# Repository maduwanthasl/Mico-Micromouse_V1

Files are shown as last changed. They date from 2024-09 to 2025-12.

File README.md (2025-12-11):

# 🐭 Mico - Micromouse V1

Welcome to the repository for **Mico**, my custom-designed micromouse robot! This project involved extensive research, component selection, PCB design, and firmware development, all aimed at building a highly capable and efficient micromouse for maze-solving applications.

## 📑 Table of Contents

1. [Project Overview](#project-overview)
2. [Hardware Components](#hardware-components)
3. [Component Comparison](#component-comparison)
4. [PCB Design](#pcb-design)
5. [Microcontroller - STM32 Blue Pill](#microcontroller---stm32-blue-pill)
6. [Firmware Development](#firmware-development)
7. [Getting Started](#getting-started)
8. [Acknowledgments](#acknowledgments)

## 📝 Project Overview

The goal of this project was to build a fully functional micromouse named **Mico** from scratch. This involved careful consideration of hardware, custom PCB design, and firmware development. Throughout the process, I selected and evaluated various components to ensure optimal performance and compatibility.

## 🔧 Hardware Components

Mico is built using carefully chosen components to maximize performance and reliability. Some of the key components include:

- **Microcontroller (MCU)**: STM32 Blue Pill
- **Power Supply**: 3.3V regulator
- **Motor Driver**: [Specify Motor Driver Here]
- **Sensors**: Infrared emitters and receivers for maze sensing
- **Motors**: Precision motors with encoders for accurate movement
- **Additional Components**: Coupling capacitors (100nF, 100V) for noise reduction, etc.

## 🔍 Component Comparison

| **Component** | **Option 1** | **Option 2** | **Notes** |
|---|---|---|---|
| **Microcontroller**  | STM32 | ATmega328P | STM32 chosen for better performance and support for PWM control |
| **Motor Type** | N20 Motor with Encoder | Coreless Motor with Custom Encoder | N20 with encoder used due to budget constraints and time |
| **Battery** | 7.4V LiPo (Downconversion) | 3.7V LiPo (Upconversion) | Upconversion method preferred for weight reduction |
| **IR Sensors** | TOF Sensors | IR Emitter and Phototransistor | IR Emitter chosen; TOF needs multiplexer, increasing response time |
| **Power Regulator**  | AM1117 (3.3V) | MT3608 Step-Up Converter | MT3608 chosen for efficient power conversion |
| **Motor Driver** | TB6612FNG | L298N | TB6612FNG preferred for compact design and compatibility |

_Table 1: Comparison of Key Components for MICO Micromouse Robot_

## 🖥️ PCB Design

I designed a custom PCB specifically for Mico to organize and integrate the various components effectively. The PCB design process involved:

- Component selection based on performance requirements.
- Layout and routing in Altium Designer.
- Prototyping and testing to ensure functionality.

The final PCB was successfully manufactured and assembled, forming the core hardware of the micromouse.

## ⚙️ Microcontroller - STM32 Blue Pill

Initially, I considered using the STM32 Black Pill due to its higher processing capability. However, due to the limited number of available analog channels, I opted for the **STM32 Blue Pill**, which provided the necessary analog inputs for the sensors. The Blue Pill proved to be reliable and sufficient for Mico’s control system.

## 📝 Firmware Development

The firmware for Mico was developed using **STM32CubeIDE**. Key aspects of the firmware include:

- **Sensor Data Processing**: Collects and processes data from the infrared sensors to detect walls and make navigational decisions.
- **Motor Control**: Controls the speed and direction of the motors for precise movement.
- **Maze Solving Algorithm**: Implements a maze-solving algorithm to navigate and solve mazes autonomously.

The firmware was written in C, leveraging various STM32 libraries for peripheral management and efficient control.

## 🚀 Getting Started

To get started with Mico's firmware and hardware setup:

1. **Clone the Repository**:
   ```bash
   git clone https://github.com/maduwanthasl/Mico-Micromouse_V1.git
   cd Mico-Micromouse_V1

## 🙏 Acknowledgments
This project was made possible thanks to the support and resources available through the open-source and embedded systems community.

Enjoy exploring Mico’s journey through maze-solving and micromouse challenges! Contributions and feedback are welcome.

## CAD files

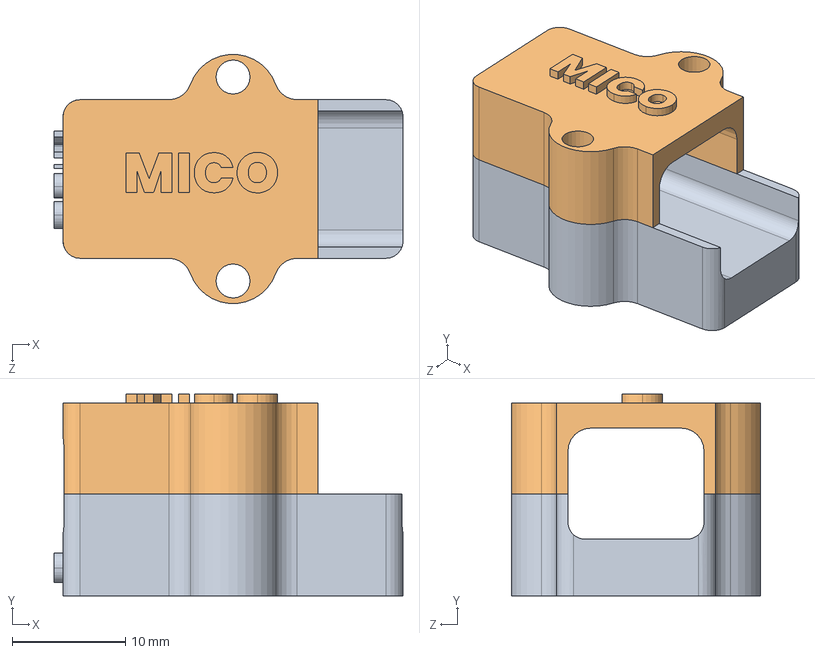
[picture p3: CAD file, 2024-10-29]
CAD files/motor assemble.SLDASM
30.8 x 17.8 x 22.0 mm
motor mounting bracket
Top mounting

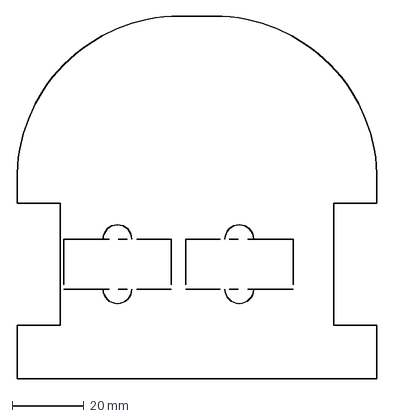
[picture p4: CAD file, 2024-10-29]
Board shape/Mico pcb board shape-2.DXF
100.8 x 101.2 mm

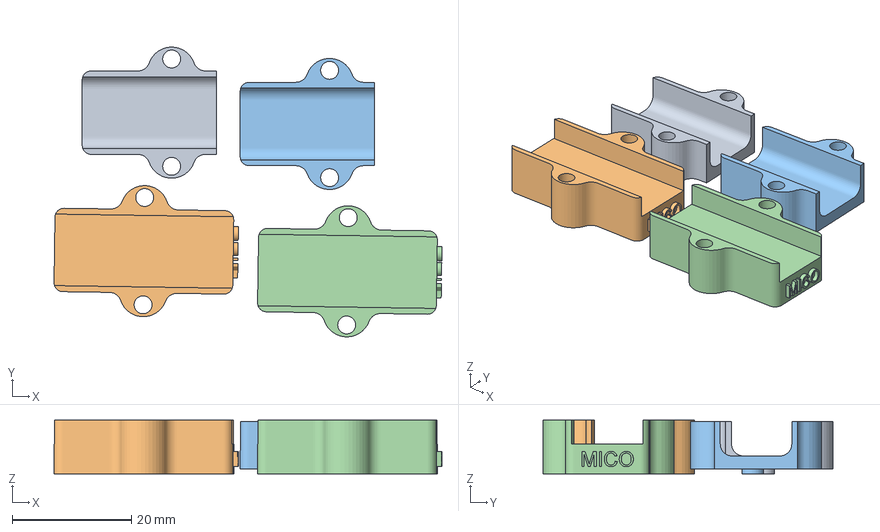
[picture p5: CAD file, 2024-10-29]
CAD files/3d slice parts/SCP_Top mounting.3mf
65.1 x 48.6 x 9.00 mm
Top mounting.STL
motor mounting bracket-L.STL
Top mounting.STL(1)
motor mounting bracket-L.STL(1)

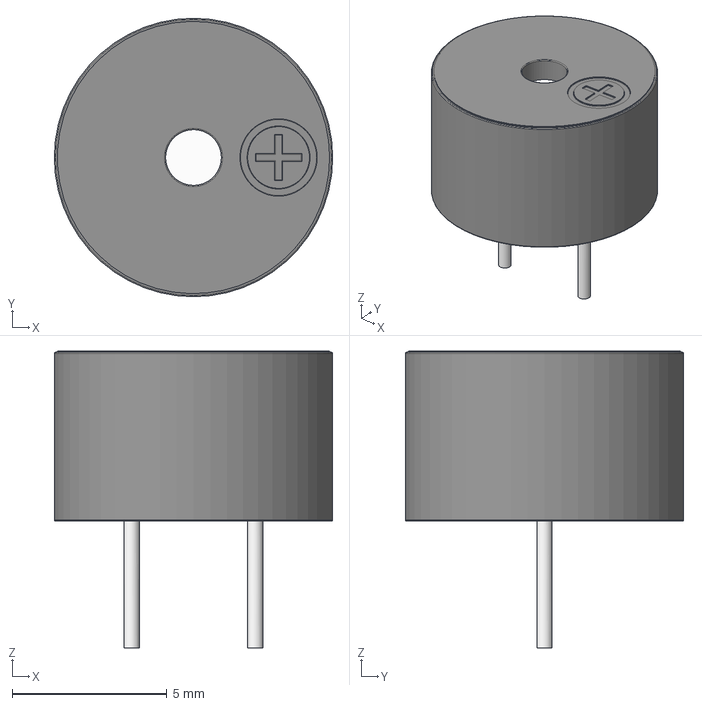
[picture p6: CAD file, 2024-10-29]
CAD files/buzzer-kls3-mt-09-1.snapshot.1/KLS3-MT-09.step
9.00 x 9.00 x 9.60 mm

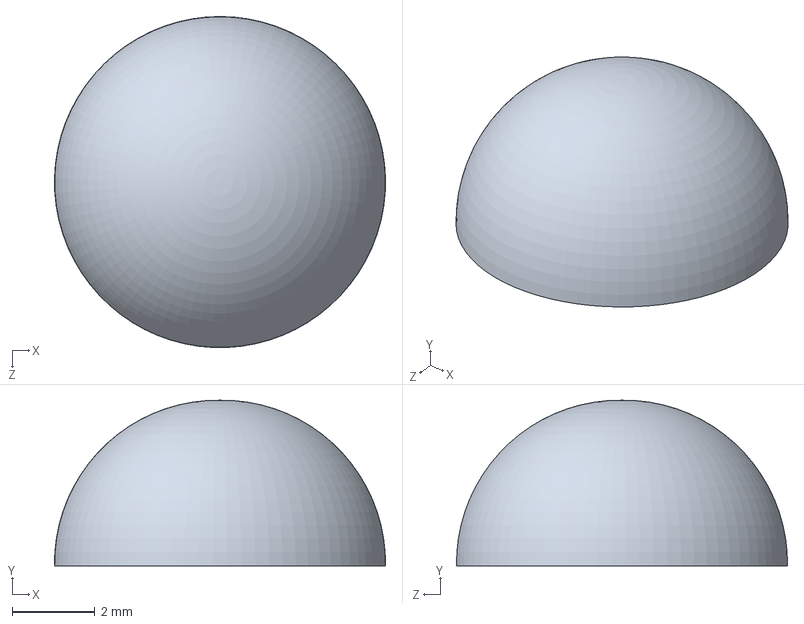
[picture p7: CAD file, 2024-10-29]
CAD files/goal.SLDPRT
8.00 x 4.00 x 8.00 mm

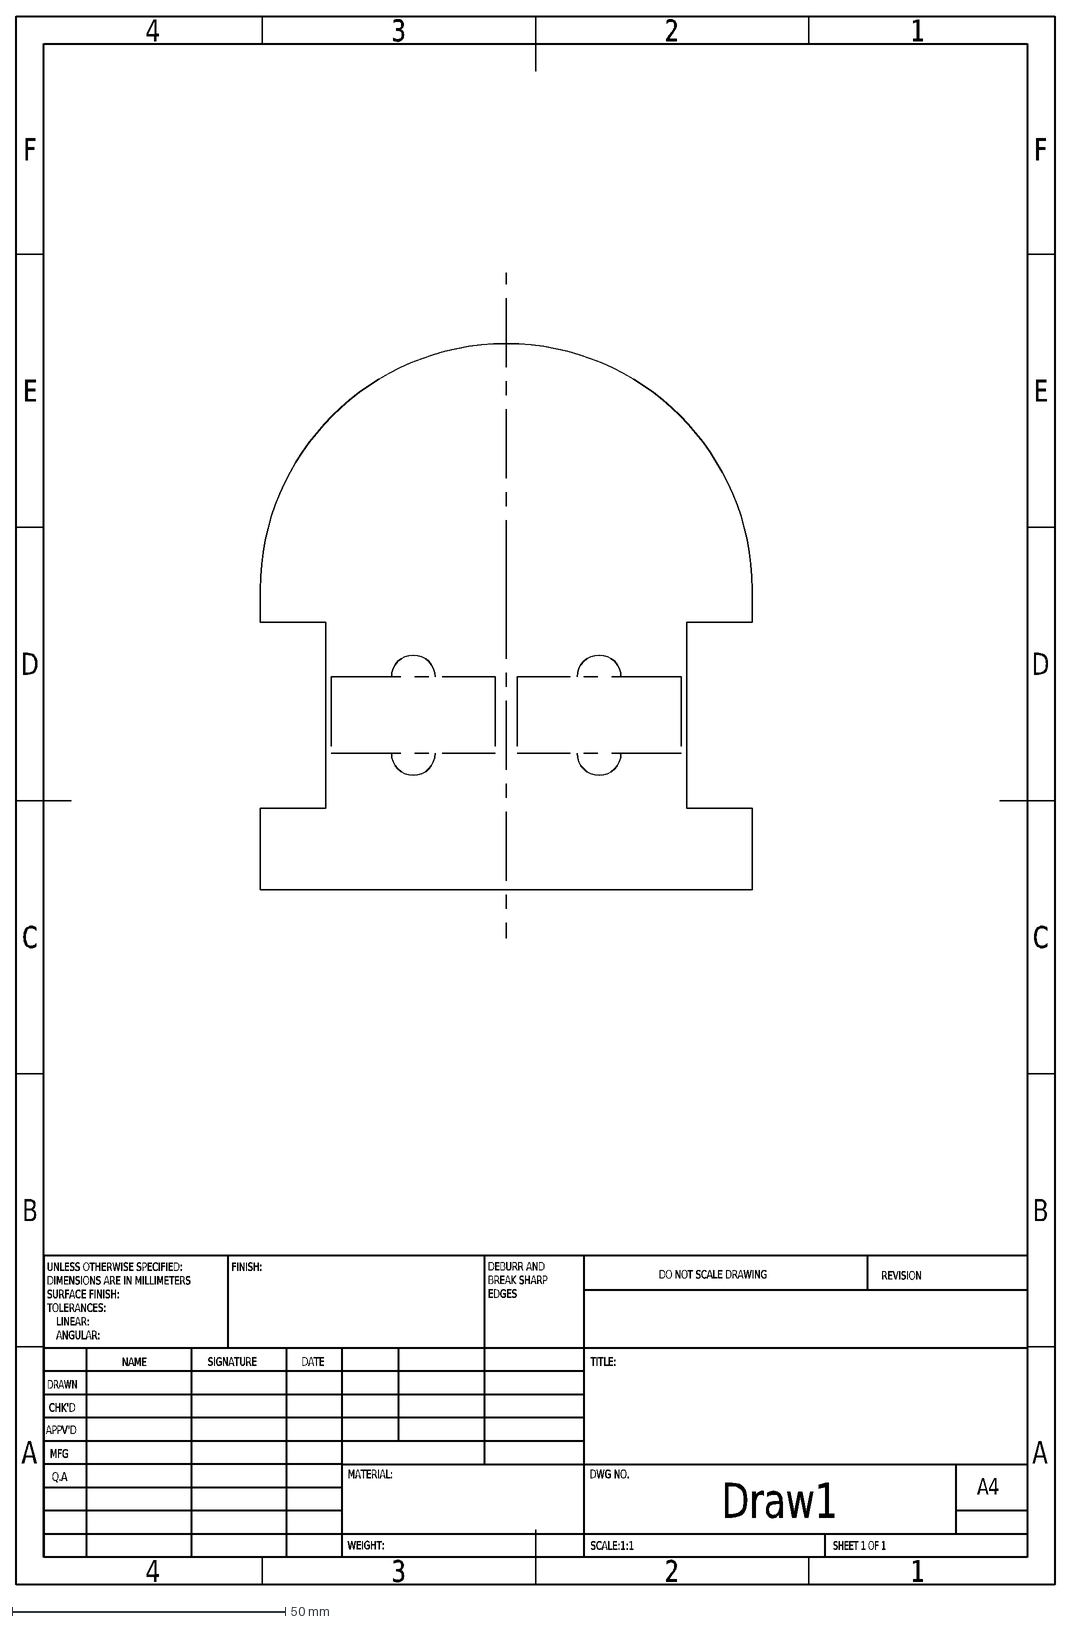
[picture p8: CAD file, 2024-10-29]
Board shape/Mico pcb board shape.DXF
A
B
C
D
E
F
4
3
2
1
DRAWN
CHK'D
APPV'D
MFG
Q.A
UNLESS OTHERWISE SPECIFIED:
DIMENSIONS ARE IN MILLIMETERS
SURFACE FINISH:
TOLERANCES:
LINEAR:
ANGULAR:
FINISH:
DEBURR AND
BREAK SHARP
EDGES
NAME
SIGNATURE
DATE
MATERIAL:
DO NOT SCALE DRAWING
REVISION
TITLE:
DWG NO.
SCALE:1:1
SHEET 1 OF 1
A4
WEIGHT:
Draw1

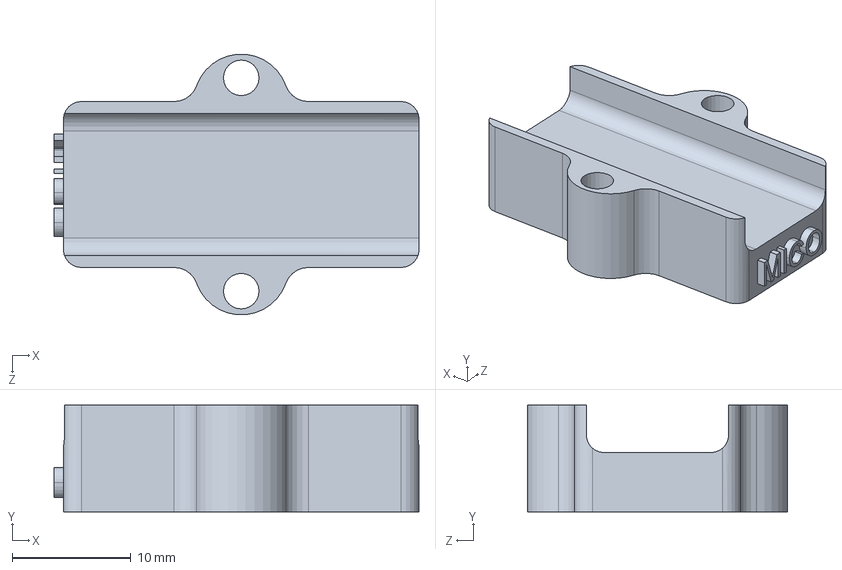
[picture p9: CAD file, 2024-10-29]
CAD files/motor mounting bracket.SLDPRT
30.8 x 9.00 x 22.0 mm

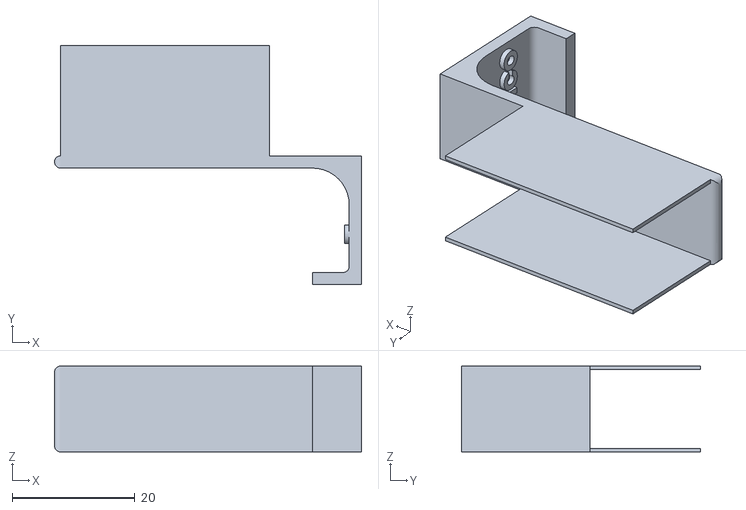
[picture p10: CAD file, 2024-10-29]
CAD files/betttry mousinting - v2.STL
50.0 x 39.0 x 14.0

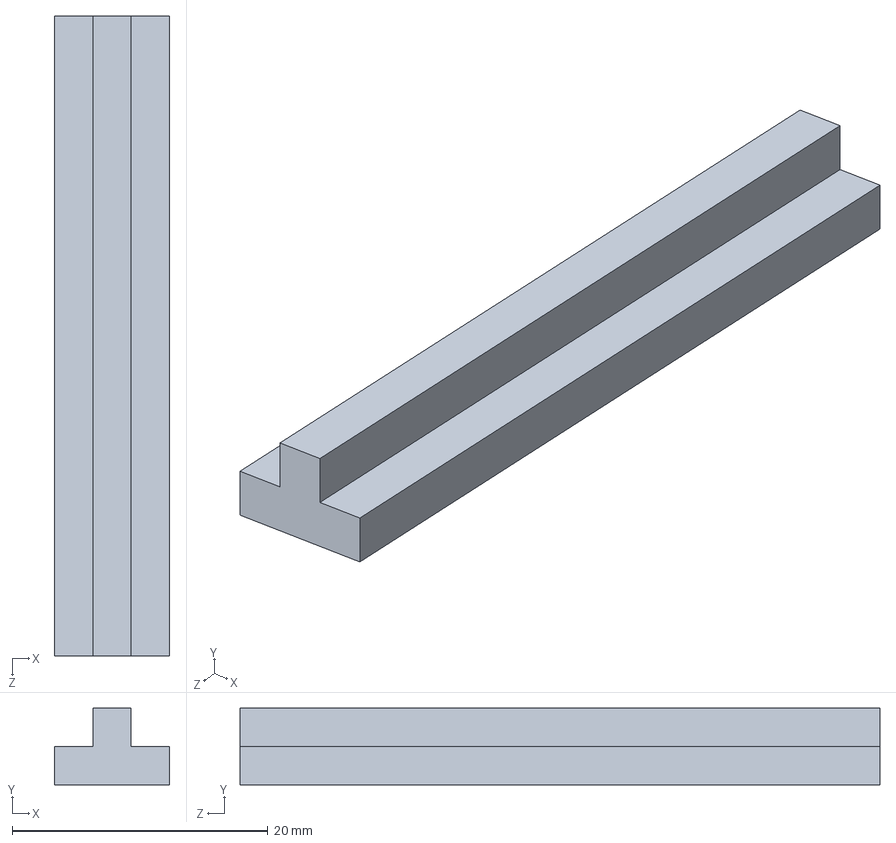
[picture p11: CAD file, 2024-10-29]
CAD files/maze part.SLDPRT
9.00 x 6.00 x 50.0 mm

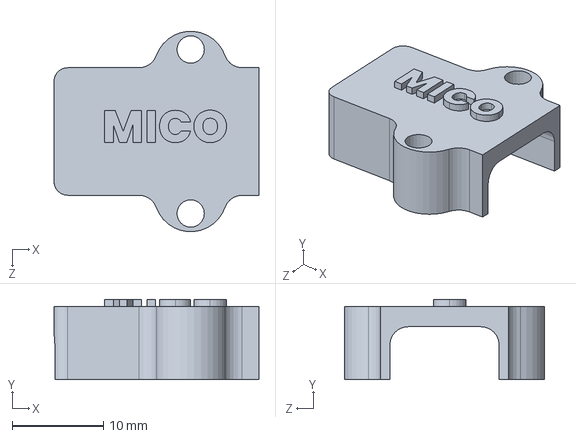
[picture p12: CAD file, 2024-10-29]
CAD files/Top mounting.SLDPRT
22.5 x 8.80 x 22.0 mm

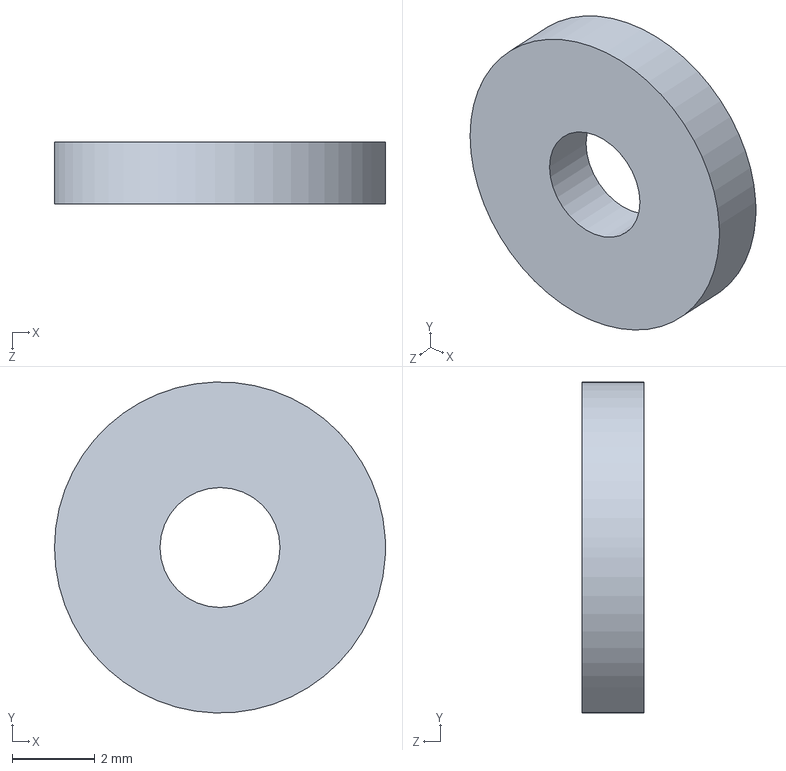
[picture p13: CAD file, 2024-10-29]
CAD files/wosher.SLDPRT
8.00 x 8.00 x 1.50 mm

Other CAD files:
CAD files/betttry mousinting.SLDPRT
CAD files/motor mounting bracket-L.STL
CAD files/goal support.STL
Board shape/Draw1.SLDDRW
CAD files/Top mounting.STL
CAD files/betttry mousinting.STL
CAD files/maze part.STL
CAD files/wosher.STL

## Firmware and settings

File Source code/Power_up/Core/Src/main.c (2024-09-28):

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
/* Includes ------------------------------------------------------------------*/
#include "main.h"

/* USER CODE BEGIN Includes */
#include <stdio.h>
#include <math.h>
#include "variables.h"
#include "push_btn_library.h"
#include "buzzer.h"
#include "motor_control.h"
#include "pid_position.h"
#include "get_ir_reading.h"
#include "mpu6050.h"
#include "rotate_angle.h"
/* USER CODE END Includes */

ADC_HandleTypeDef hadc1;
ADC_HandleTypeDef hadc2;

I2C_HandleTypeDef hi2c2;

TIM_HandleTypeDef htim1;
TIM_HandleTypeDef htim3;
TIM_HandleTypeDef htim4;

void SystemClock_Config(void);
static void MX_GPIO_Init(void);
static void MX_TIM1_Init(void);
static void MX_TIM4_Init(void);
static void MX_TIM3_Init(void);
static void MX_ADC1_Init(void);
static void MX_ADC2_Init(void);
static void MX_I2C2_Init(void);
/**
  * @brief  The application entry point.
  * @retval int
  */
int main(void)
{

  /* MCU Configuration--------------------------------------------------------*/

  /* Reset of all peripherals, Initializes the Flash interface and the Systick. */
  HAL_Init();

  /* Configure the system clock */
  SystemClock_Config();

  /* Initialize all configured peripherals */
  MX_GPIO_Init();
  MX_TIM1_Init();
  MX_TIM4_Init();
  MX_TIM3_Init();
  MX_ADC1_Init();
  MX_ADC2_Init();
  MX_I2C2_Init();
  /* USER CODE BEGIN 2 */
  HAL_GPIO_WritePin(LED_PWR_GPIO_Port, LED_PWR_Pin, GPIO_PIN_SET);
  HAL_TIM_PWM_Start(&htim1, TIM_CHANNEL_3);
  HAL_TIM_PWM_Start(&htim4, TIM_CHANNEL_3);
  HAL_TIM_PWM_Start(&htim4, TIM_CHANNEL_4);
  HAL_TIM_Encoder_Start_IT(&htim3, TIM_CHANNEL_1);
  HAL_TIM_Encoder_Start_IT(&htim3, TIM_CHANNEL_2);

  buzzer_power_up_tone();

  __HAL_TIM_SET_COUNTER(&htim3, 0); // Reset the counter

  Calibrate_IR_Sensors();
//  HAL_Delay(2000);
//  MPU6050_Init();
//  MPU6050_CalibrateGyro();
//  HAL_Delay(2000);


  /* USER CODE END 2 */

  /* Infinite loop */
  /* USER CODE BEGIN WHILE */
  while (1)
  {
//	  __HAL_TIM_SET_COUNTER(&htim3, 0); // Reset the counter
    // Check if push button is pressed (adjust logic based on pull-up/pull-down configuration)
	  push_btn(PUSH_BTN2_GPIO_Port, PUSH_BTN2_Pin, LED_COM_GPIO_Port, LED_COM_Pin);
	  Get_IR_Readings();
	  motor_control_loop_with_pid();
    /* USER CODE END WHILE */

    /* USER CODE BEGIN 3 */
  }
  /* USER CODE END 3 */
}

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


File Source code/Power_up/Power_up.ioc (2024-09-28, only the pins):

Mcu.UserName=STM32F103C8Tx
PA0-WKUP.GPIO_Label=LF_RECEIVER
PA0-WKUP.Signal=ADCx_IN0
PA1.GPIO_Label=LD_RECEIVER
PA1.Signal=ADCx_IN1
PA10.Signal=S_TIM1_CH3
PA11.GPIO_Label=LED_FAN
PA11.Signal=GPIO_Output
PA12.GPIO_Label=PUSH_BTN
PA12.Signal=GPIO_Input
PA13.Signal=SYS_JTMS-SWDIO
PA14.Signal=SYS_JTCK-SWCLK
PA15.GPIO_Label=LED_RF
PA15.Signal=GPIO_Output
PA2.GPIO_Label=LMF
PA2.Signal=GPIO_Output
PA3.GPIO_Label=LMB
PA3.Signal=GPIO_Output
PA4.GPIO_Label=RD_RECEIVER
PA4.Signal=ADCx_IN4
PA5.GPIO_Label=RF_RECEIVER
PA5.Signal=ADCx_IN5
PA6.GPIO_Label=RMF
PA6.Signal=GPIO_Output
PA7.GPIO_Label=RMB
PA7.Signal=GPIO_Output
PA8.GPIO_Label=LED_SPD
PA8.Signal=GPIO_Output
PA9.GPIO_Label=LED_COM
PA9.Signal=GPIO_Output
PB0.GPIO_Label=ENA_RM
PB0.Signal=GPXTI0
PB10.GPIO_Label=SCL_GYRO
PB10.Signal=I2C2_SCL
PB11.GPIO_Label=SDA_GYRO
PB11.Signal=I2C2_SDA
PB12.GPIO_Label=LF_EMMITER
PB12.Signal=GPIO_Output
PB13.GPIO_Label=D_EMMITER
PB13.Signal=GPIO_Output
PB14.GPIO_Label=RF_EMMITER
PB14.Signal=GPIO_Output
PB15.GPIO_Label=LED_PWR
PB15.Signal=GPIO_Output
PB3.GPIO_Label=LED_LF
PB3.Signal=GPIO_Output
PB4.GPIO_Label=ENA_LM
PB4.Signal=S_TIM3_CH1
PB5.GPIO_Label=ENB_LM
PB5.Signal=S_TIM3_CH2
PB7.GPIO_Label=PUSH_BTN2
PB7.Signal=GPIO_Input
PB8.GPIO_Label=RM_PWM
PB8.Signal=S_TIM4_CH3
PB9.GPIO_Label=LM_PWM
PB9.Signal=S_TIM4_CH4
PC14-OSC32_IN.GPIO_Label=LED_RD
PC14-OSC32_IN.Signal=GPIO_Output
PC15-OSC32_OUT.GPIO_Label=LED_LD
PC15-OSC32_OUT.Signal=GPIO_Output
PD0-OSC_IN.Signal=RCC_OSC_IN
PD1-OSC_OUT.Signal=RCC_OSC_OUT

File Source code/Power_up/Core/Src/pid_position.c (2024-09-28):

/*
 * pid_position.c
 *
 *  Created on: Sep 23, 2024
 *      Author: Ama
 */

#include "pid_position.h"

// Define variables

uint32_t count2 = 0;
volatile uint32_t last_interrupt_time = 0;  // To store the time of the last valid interrupt
int16_t count = 0;

// Callback function to capture encoder count
void HAL_TIM_IC_CaptureCallback(TIM_HandleTypeDef* htim3) {
    counter = __HAL_TIM_GET_COUNTER(htim3);
    count = (int16_t)counter;

}

// External interrupt callback (for debouncing)
void HAL_GPIO_EXTI_Callback(uint16_t GPIO_Pin) {
    uint32_t current_time = HAL_GetTick();  // Get current system tick (milliseconds)

    if (current_time - last_interrupt_time > 2) {  // Debounce logic
        count2 += 1;
        last_interrupt_time = current_time;
    }
}

// Initialize the PID controller
void PID_Init(PID_Controller *pid, float Kp, float Ki, float Kd, float setpoint) {
    pid->Kp = Kp;
    pid->Ki = Ki;
    pid->Kd = Kd;
    pid->setpoint = setpoint;
    pid->integral = 0.0f;
    pid->previous_error = 0.0f;
}

// Compute the PID output
float PID_Update(PID_Controller *pid, float current_value) {
    float error = pid->setpoint - current_value;

    // Integral term with windup guard
    pid->integral += error;
    if (pid->integral > 1000) pid->integral = 1000;  // Clamp integral
    if (pid->integral < -1000) pid->integral = -1000;

    float derivative = error - pid->previous_error;

    // Calculate control signal
    float output = pid->Kp * error + pid->Ki * pid->integral + pid->Kd * derivative;

    pid->previous_error = error;

    return output;
}

// Define PID controller instance
PID_Controller pid;
IR_Control_PIDController ir_control_pid_instance;

#define ERROR 10
#define TARGET_POS 280
#define TARGET_COUNT (TARGET_POS + ERROR)   // Target encoder count

#define PID_KP 0.2f          // Proportional gain
#define PID_KI 0.005f        // Integral gain
#define PID_KD 0.05f         // Derivative gain

float control_signal;

// Motor control loop with PID and overshoot correction
void motor_control_loop_with_pid(void) {
//    PID_Init(&pid, PID_KP, PID_KI, PID_KD, TARGET_COUNT);
    ir_control_pid_init(&ir_control_pid_instance,0.09f,0.00f,0.08f);
//    ir_control_output = 0;

    while (1) {
//        control_signal = PID_Update(&pid, (float)count);  // Get control signal from PID
    	Get_IR_Readings();
        ir_control_output = ir_control_pid_function(&ir_control_pid_instance, LD_reading, RD_reading, LD_min, RD_min);
        control_signal = 20;


        if (count < TARGET_COUNT) {
            // Clamp control signal for PWM
//            if (control_signal > 20) control_signal = 20;
//            if (control_signal < -20) control_signal = -20;
            if (ir_control_output > 10) ir_control_output = 10;
            if (ir_control_output < -10) ir_control_output = -10;

            if ((count <= TARGET_COUNT) && (count > TARGET_POS)) {
                count = 0;
                ir_control_output = 0;
                stop();   // Stop the motor
                HAL_GPIO_WritePin(LED_SPD_GPIO_Port, LED_SPD_Pin, GPIO_PIN_SET);  // Indicate stop with LED
                HAL_Delay(2000);
                HAL_GPIO_WritePin(LED_SPD_GPIO_Port, LED_SPD_Pin, GPIO_PIN_RESET);  // Indicate stop with LED
                break;
            }

            // Adjust motor speed based on control signal
            if (control_signal > 0) {
                forward(((uint8_t)control_signal + ir_control_output), ((uint8_t)control_signal - ir_control_output));  // Move forward
            } else {
                backward((uint8_t)(-control_signal), (uint8_t)(-control_signal));  // Move backward
            }
        }
    }
}


// Initialize PID controller
void ir_control_pid_init(IR_Control_PIDController *ir_control_pid, float Kp, float Ki, float Kd) {
	ir_control_pid->Kp = Kp;
	ir_control_pid->Ki = Ki;
	ir_control_pid->Kd = Kd;
	ir_control_pid->previous_error = 0.0f;
	ir_control_pid->integral = 0.0f;
}

float ir_control_error;

// PID control function based on LD and RD readings
float ir_control_pid_function(IR_Control_PIDController *ir_control_pid, uint16_t LD_reading, uint16_t RD_reading, uint16_t LD_min, uint16_t RD_min) {
	Get_IR_Readings();
    // Find the maximum of LD_reading and RD_reading
    if ((LD_reading -LD_min) > (RD_reading-RD_min)+300) {
        // Calculate error as LD_reading - LD_min
    	ir_control_error = LD_reading - LD_min;
    }
    else if ((LD_reading -LD_min)+300 < (RD_reading-RD_min)){
        // Calculate error as RD_reading - RD_min (you can add RD_min if required)
    	ir_control_error = RD_reading - RD_min; // You can change this depending on your logic
    }
    else{
    	ir_control_error = 0;
    }

    // PID calculations
    ir_control_pid->integral += ir_control_error; // Accumulate integral
    float derivative = ir_control_error - ir_control_pid->previous_error; // Calculate derivative
    ir_control_output = (ir_control_pid->Kp * ir_control_error) + (ir_control_pid->Ki * ir_control_pid->integral) + (ir_control_pid->Kd * derivative); // PID formula

    // Store current error for next iteration
    ir_control_pid->previous_error = ir_control_error;

    // Return the PID output
    if ((LD_reading -LD_min) < (RD_reading-RD_min)) ir_control_output = -ir_control_output;
    return (ir_control_output/16);
}

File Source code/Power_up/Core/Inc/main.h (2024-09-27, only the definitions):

#define LED_RD_Pin GPIO_PIN_14
#define LED_RD_GPIO_Port GPIOC
#define LED_LD_Pin GPIO_PIN_15
#define LED_LD_GPIO_Port GPIOC
#define LF_RECEIVER_Pin GPIO_PIN_0
#define LF_RECEIVER_GPIO_Port GPIOA
#define LD_RECEIVER_Pin GPIO_PIN_1
#define LD_RECEIVER_GPIO_Port GPIOA
#define LMF_Pin GPIO_PIN_2
#define LMF_GPIO_Port GPIOA
#define LMB_Pin GPIO_PIN_3
#define LMB_GPIO_Port GPIOA
#define RD_RECEIVER_Pin GPIO_PIN_4
#define RD_RECEIVER_GPIO_Port GPIOA
#define RF_RECEIVER_Pin GPIO_PIN_5
#define RF_RECEIVER_GPIO_Port GPIOA
#define RMF_Pin GPIO_PIN_6
#define RMF_GPIO_Port GPIOA
#define RMB_Pin GPIO_PIN_7
#define RMB_GPIO_Port GPIOA
#define ENA_RM_Pin GPIO_PIN_0
#define ENA_RM_GPIO_Port GPIOB
#define SCL_GYRO_Pin GPIO_PIN_10
#define SCL_GYRO_GPIO_Port GPIOB
#define SDA_GYRO_Pin GPIO_PIN_11
#define SDA_GYRO_GPIO_Port GPIOB
#define LF_EMMITER_Pin GPIO_PIN_12
#define LF_EMMITER_GPIO_Port GPIOB
#define D_EMMITER_Pin GPIO_PIN_13
#define D_EMMITER_GPIO_Port GPIOB
#define RF_EMMITER_Pin GPIO_PIN_14
#define RF_EMMITER_GPIO_Port GPIOB
#define LED_PWR_Pin GPIO_PIN_15
#define LED_PWR_GPIO_Port GPIOB
#define LED_SPD_Pin GPIO_PIN_8
#define LED_SPD_GPIO_Port GPIOA
#define LED_COM_Pin GPIO_PIN_9
#define LED_COM_GPIO_Port GPIOA
#define LED_FAN_Pin GPIO_PIN_11
#define LED_FAN_GPIO_Port GPIOA
#define PUSH_BTN_Pin GPIO_PIN_12
#define PUSH_BTN_GPIO_Port GPIOA
#define LED_RF_Pin GPIO_PIN_15
#define LED_RF_GPIO_Port GPIOA
#define LED_LF_Pin GPIO_PIN_3
#define LED_LF_GPIO_Port GPIOB
#define ENA_LM_Pin GPIO_PIN_4
#define ENA_LM_GPIO_Port GPIOB
#define ENB_LM_Pin GPIO_PIN_5
#define ENB_LM_GPIO_Port GPIOB
#define PUSH_BTN2_Pin GPIO_PIN_7
#define PUSH_BTN2_GPIO_Port GPIOB
#define RM_PWM_Pin GPIO_PIN_8
#define RM_PWM_GPIO_Port GPIOB
#define LM_PWM_Pin GPIO_PIN_9
#define LM_PWM_GPIO_Port GPIOB

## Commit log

2024-09-07 Adding some effect for buzzer
    [Buzzer_effect Debug.cfg]
2024-09-23 POWER UP
    HERE I ADD POWERING UP + BUZZER + ENCODER COUNTUNG + MOTOR ROTATION
    [Power_up Debug.cfg, Power_up_copy Debug.cfg]
2024-09-23 GYRO-MPU6050
    THIS IS SIMPLE CODE THAT CAN MESSURE ANGLES, BUT HERE ANGLES ARE NOT ACCURATE
    [GYRO-MPU6050 Debug.cfg]
2024-09-23 Add Complementary Filter
    Here i add Complementary Filter to measure precise angle
2024-09-23 Add following
    Add ir sensor readings + pid position control
2024-09-23 Encoder counting
    Here this code use for counting n20 motor encoders.
    [Motor encoder Debug.cfg]
2024-09-27 PRESICE MOTOR CONTROL
    ADD COMPLEMENTARY FILTER FOR BOTH IR CONTROL SIGNAL AND COUNT CONTROL SINGAL
2024-10-29 Board Shape
    [Draw1.SLDDRW, Mico pcb board shape-2.DXF, Mico pcb board shape.DXF]
2024-10-29 Designed cad files
    [KLS3-MT-09.step, SCP_Top mounting.3mf, Top mounting.SLDPRT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]
2024-10-29 Source code
    [Buzzer Debug.cfg, Buzzer_effect Debug.cfg, GYRO-MPU6050 Debug.cfg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]
2024-10-29 PCB libraries
    [Draw1.SLDDRW, Mico pcb board shape-2.DXF, Mico pcb board shape.DXF]

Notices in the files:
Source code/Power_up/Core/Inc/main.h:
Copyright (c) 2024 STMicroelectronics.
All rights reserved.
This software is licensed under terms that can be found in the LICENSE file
